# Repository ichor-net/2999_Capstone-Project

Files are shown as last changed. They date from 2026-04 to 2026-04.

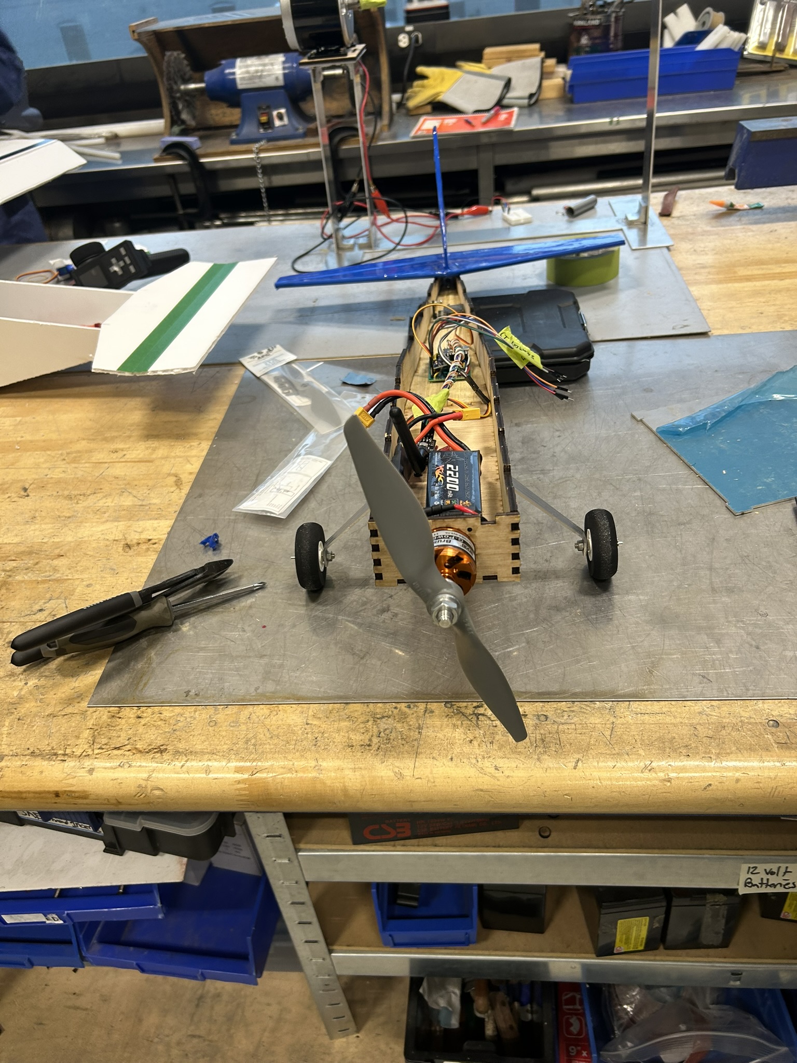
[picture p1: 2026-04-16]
Media/Photos/Assembly (6).JPEG

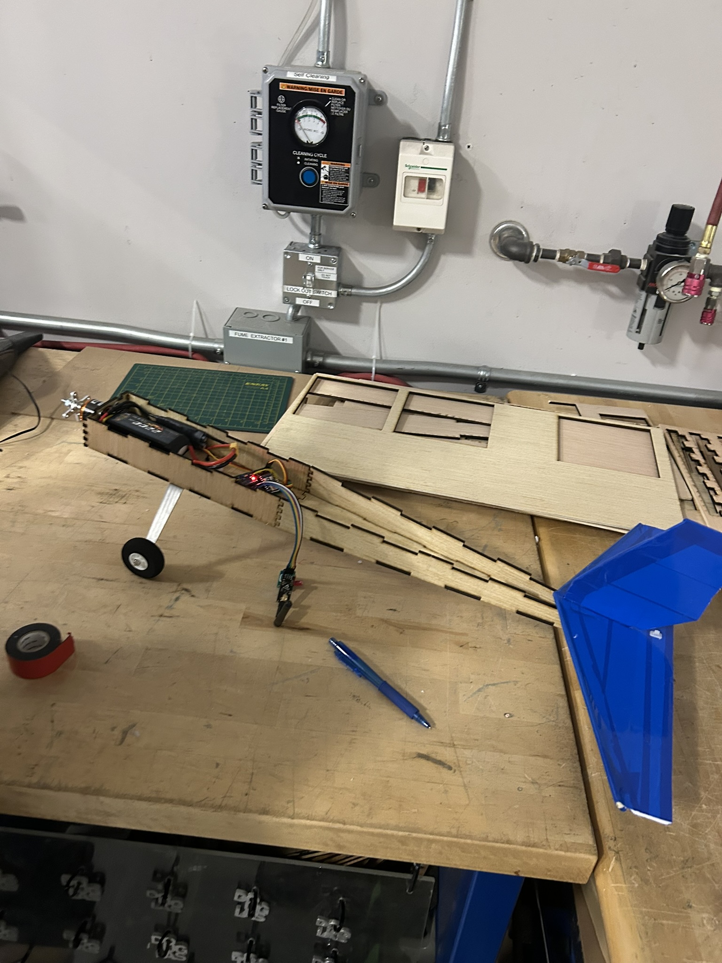
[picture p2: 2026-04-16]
Media/Photos/Assembly (1).JPEG

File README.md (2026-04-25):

# 2999 Capstone Project
Repo for rc plane project files

[Build log](/Reports/Build_Log.md)

All files relating to the project have been organized and uploaded here. I don't really have much to say here •_•

##  
_© 2026 Maximus Larouche, Brendan Morisson. This work is licensed under the Creative Commons Attribution 4.0 International License (CC BY 4.0)._

_You may use, share, and adapt this work for educational purposes, provided proper credit is given to the original authors._

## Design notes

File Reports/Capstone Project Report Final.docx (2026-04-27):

# Remote Controlled Plane and Controller

# ENGR 2999, Douglas College

# Maximus Larouche, Brendan Morrison

# 20/04/2026

# Abstract

This capstone project details the development of a semi-autonomous remote-controlled aircraft and its custom handheld controller. The project transitioned from an initial 3D-printed design to a 1250g laser-cut plywood airframe to ensure structural rigidity for a high-power 4S propulsion system. Aerodynamic analysis utilizing the lift equation resulted in a 62.5-inch wingspan, providing a 55% lift surplus and a significant safety margin for flight testing. The integrated electronics system features a custom RP2350-based control board and a 2.4GHz LoRa radio link, achieving a 1.5:1 thrust-to-weight ratio that places the aircraft in the "sport flyer" category. While core flight systems, including 100Hz PWM signal transmission and tail-dragger landing gear, are fully operational, secondary features such as IMU-based stability and OLED telemetry were deferred to prioritize link reliability. This platform serves as a functional foundation for future multicore software optimizations and real-world environmental validation.

# Introduction

For our project, the moto for our plane is as follows: “it only has to fly, but that doesn’t mean it has to land”. The plane was originally based around the Cessna 182 from which we steered our own design to fit our needs and constraints. The plane’s wings, aerodynamics, and power systems were originally designed for around a 1:1 thrust to weight ratio, however the final weight was around 300g less than our original target, thus resulting in a 1.5:1 ratio, putting it comfortably in the sport flyer category.

The plane uses a 9x6 2-blade propeller with 1450kV brushless motor, powered by a 60A ESC and a 2200mAh 4S LiPo battery. The plane’s communication comes from a 2.4GHz LoRa radio antenna, with a custom soldered RP2350 based control board handling the communication and servo control. The controller uses a slide potentiometer for the throttle and a joystick for the pitch and roll. The controller uses the same MCU and antenna, with a built-in battery and LiPo charging circuit feeding the board.

The software, while functional, is still undergoing improvements and optimizations to allow greater levels of control, and stability. The software is written in Arduino with the ArduinoPico core, with the current version only operating on the single core of the RP2350 on both devices. The software is written to be lightweight and efficient to allow for the most resources to be dedicated to transmitting and receiving data for the antenna.

On the mechanical side the project was initially conceived as a 3D-printed project, the development underwent a significant pivot toward 2D CAD and laser-cut plywood construction to meet fabrication deadlines and ensure a robust platform for the high power propulsion system. The mechanical team focused on optimizing wing area via aerodynamic lift equations and implementing a tail-dragger landing gear configuration to maximize ground clearance. This platform serves as the foundation for the integrated avionics and flight control software.

# Bill of Materials

Item | Quantity | Unit Cost | Cost
Soldering / Prototyping Materials (https://www.amazon.ca/Tnisesm-Connector-Terminal-Prototype-Soldering/dp/B0BWDZK4KZ/ref=sr_1_9?sr=8-9) | 1 (pack) | $16.99 | $16.99
1450Kv Motor (https://www.amazon.ca/D3536-Brushless-Multi-copter-Fixed-wing-Helicopters（D3536/dp/B0D3DWFDG7?th=1) | 1 | $30.81 | $30.81
60A ESC (https://www.amazon.ca/Brushless-2-0mm-fixed-wing-aircraft-helicopter/dp/B0FRM7X984?th=1) | 1 | $44.79 | $44.79
14.8v 2200mAh Battery (https://www.amazon.ca/MELASTA-2200mAh-Airplane-Helicopter-Quadcopter/dp/B01M1ICI8Z) | 1 | $32.99 | $32.99
IMU/Gyroscope module (MPU6050) (https://www.amazon.ca/WayinTop-Gyroscope-Accelerometer-Converter-Arduino/dp/B07P5YXBXV?s=electronics) | 1 | $4.33 | $4.33
Slide Potentiometers (https://www.mouser.ca/ProductDetail/Same-Sky/PTNS2-3010M-B10?qs=6avfeC6zeS4zh8RaIzrOLg%3D%3D) | 1 | $2.55 | $2.55
Toggle Switches (https://www.amazon.ca/Hoypeyfiy-Miniature-Terminals-Automotive-Instrument/dp/B0D89YZPC1) | 1 | $1.07 | $1.07
NRF24L01 PA + LNA Antenna Module (https://www.amazon.ca/CANADUINO®-nRF24L01-2-4GHz-wireless-modem/dp/B06VT3WS66) | 2 | $4.95 | $9.90
WaveShare RP2350-Zero modules (https://www.amazon.ca/Waveshare-RP2350-Zero-Development-Microcontroller-Dual-Architecture/dp/B0DYTVCF2H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) | 2 | $11.50 | $22.99
Joystick Modules (https://www.amazon.ca/Partstower-Joystick-Breakout-Arduino-arduino/dp/B06Y1TG2QL?s=electronics) | 1 | $5.75 | $5.75
MG90s 9g Servos | 3 | ~$4.43 | ~$13.30
9x6 Two Blade Propeller | 1 | $8.90 | $8.90
Miscellaneous electrical components (already had / found them) | - The Insides of a CAT6 Ethernet Cable (wire) - SSD1306 128x84 OLED Display (1x) - EC11 Rotary Encoder (1x) - XL6009 Boost Converter (1x) - TP4056 Battery Charger (1x) - Scavenged Lithium Ion Cell (1x) - 10k Resistors (5x) - 100uF Electrolytic Capacitor (2x) - 10nF Ceramic Capacitors (7x)
Landing Gear (https://www.amazon.ca/dp/B01KRIDXXA?ref=ppx_yo2ov_dt_b_fed_asin_title) | 1 | $21.99 | $21.99
Packing Tape (https://www.princessauto.com/en/2-in-x-100-m-packing-tape-assorted-colours/product/PA0009523648) | 1 | $2.99 (ON SALE) | $2.99
Foam Board (https://www.dollartree.com/readi-board-white-foam-boards/809955) | 3 | $1.25 | $3.75
Control Surface Hardware (https://www.amazon.ca/dp/B0CR76BYXQ?ref=ppx_yo2ov_dt_b_fed_asin_title) | 1 | $18.99 | $18.99
¼” Wooden Dowel (https://www.homedepot.ca/product/alexandria-moulding-hardwood-dowel-1-4-in-x-48-in-blue/1000115241) | 1 | $3.97 | $7.94
Miscellaneous mechanical components (already had / found them) | - ~500g Plywood - M3 Bolts, Nuts, Lock Washers (x6) - M4 Bolts, Nuts (x2)

Total Cost: $250.03

# Design and Changelog

## Mechanical Systems

A. Specifications:
1. Wing Loading and Lift: For a 62.5-inch wingspan with a 7-inch chord, the total wing area is approximately 437.5 square inches or 0.2823 square meters. At a total weight of ~1250g, the wing loading is low enough to allow for stable flight at speeds achievable by a 1450KV motor and a 9-inch propeller.
2. Structural Material: The fuselage is constructed from 5mm laser-cut plywood using friction fit construction with a small caveat. This provides the necessary torsional rigidity to support the battery and motor torque that wouldn’t be possible using only foam in the fuselage. The small caveat is the friction fit in the middle of the plane started to fail upon final assembly and is now aided with tape and epoxy along the area that joins together.
3. Landing Gear Configuration: A tail-dragger configuration was selected to maximize the propeller clearance (~5 inches) and simplify assembly due to time constraints. This configuration requires the main gear to be positioned 3 inches ahead of the Centre of Gravity to prevent “nosing over” during taxi.
4. Propeller Clearance: For a 9-inch propeller, a minimum ground clearance of 0.5 inches at a level position is required. In the three-point stance, the tail-dragger setup further increases this clearance to ~2.5 inches, protecting the drivetrain during takeoff.
5. Control Surface Proportion: The elevator and ailerons were designed to be approximately 30% of the wing and horizontal stabilizer chord respectively. This ratio is considered good practice in RC Plane design to ensure sufficient pitch authority for a short-couple 28-inch (0.700m) fuselage without overwhelming the 9g servos.
B. Math:
1. A primary objective of the design phase was determining the optimal wing area (S) required to generate sufficient lift for the airframe. The design was calculated based on an initial target mass of 1.5 kg to provide a conservative safety margin. In the absence of wind tunnel data for the specific Armin wing profile, established aerodynamic constants and conservative RC aircraft coefficients were utilized in the lift equation. This "worst-case" design approach ensured that the resulting 62.5-inch wingspan would possess a substantial lift surplus, accommodating the final system weight while maintaining a low stall velocity for safe flight testing.

S=Minimum Wing Area

L=Lift=(1.50 kg)(9.81m/(s^2))=12.3 N

ρ=Air Density=1.225(kg)/(m^3)

v=Target Takeoff Speed=10 m/s

C_L =Max Coefficient of Lift=1.1

L=1/2ρv^2 SC_L

S= (2L)/(ρv^2 C_L)= (2(12.3))/((1.225)(10)^2 (1.1))=0.182 m^2 ≈282 in^2

Before construction, the minimum wing area (S) was calculated using the lift equation, assuming a target takeoff velocity of 10 m/s and a Coefficient of Lift of 1.1. While the mathematical minimum area required to support the mass was, a design area of (a 62.5-inch span) was selected. This provides a 55% lift surplus, lowering the stall speed and providing a broader safety margin for manual flight testing. Furthermore, this dimension was strategically chosen to align with the standard stock lengths of the foam board material, optimizing the building process by eliminating the need for span-wise cuts and reducing potential points of structural weakness at the wingtips.

The following is the changelog on the mechanical side:

Part | Description | Change List | Conclusions

Fuselage

Front

The front/motor mount section of the aircraft

RCPlaneSkeletonFront1

- First draft of the front bringing the 3d sketch to reality

RCPlaneSkeletonFront2

- Added cross members to the area that connects to rest of fuselage to increase strength (includes improved geometry)

RCPlaneSkeletonFront3

- Improved Geometry

RCPlaneFront1

- Design switch from 3d modelling and printing to 2d CAD and laser cutting

RCPlaneFront2

- Added bolt holes to mount the motor to the front

RCPlaneSkeleton(Front/Middle/Tail) Conclusions:

- Entering the project with limited 3D modeling experience presented significant challenges, causing the initial design phase to exceed the projected timeline before a presentable model was achieved.
- The failure of the initial 3D-printed fuselage acted as a critical turning point. Recognizing that complex 3D modeling was no longer feasible within the remaining timeframe, the design philosophy shifted to 2D CAD and laser cutting. This allowed for the utilization of familiar fabrication methods to maintain project momentum.

RCPlane(Front/Top) Conclusions:

- Transitioning to laser-cut plywood proved to be the correct strategic decision. Although this resulted in a more utilitarian and less aerodynamic aesthetic, it enabled the mechanical team to rapidly produce a functional prototype by leveraging core engineering principles and prior fabrication experience.

Fuselage Middle

The middle section of the fuselage responsible for holding most of the avionics

RCPlaneSkeletonMiddle1

- First draft of the front bringing the 3d sketch to reality

RCPlaneSkeletonMiddle2

- Shortened the geometry as initial design was too large to 3d print in one piece

RCPlaneSkeletonMiddle3

- Added cross members

RCPlaneTop1

- Design switch from 3d modelling and printing to 2d CAD and laser cutting. Implemented a live hinge to create a seamless, strong one-piece fuselage

RCPlaneTop2

- Scrapped the live hinge idea and shortened to original 3d sketch geometry

RCPlaneTop3

- Added bolt holes and area for servo wires from wings to connect to microcontroller in fuselage. This area also acts as cooling for the battery and esc and lets antenna reach exterior of plane

Fuselage Tail | The tail section of the fuselage | RCPlaneSkeletonTail - First draft of the front bringing the 3d sketch to reality RCPlaneSkeletonTailFront - Shortened the geometry as initial design was too large to 3d print in one piece RCPlaneSkeletonTailRear1 - Shortened the geometry as initial design was too large to 3d print in one piece RCPlaneSkeletonTailRear2 - Improved Geometry
Wings and Horizontal Stabilizer | Wings, horizontal stabilizer and control surfaces that create the lift for the plane | | Definitive conclusions remain pending successful flight testing. While the integrated systems currently function as intended, dynamic flight loads present risks to the wing and stabilizer connections. To mitigate potential failure, epoxy joints and bolt interfaces have been reinforced, ensuring structural integrity can withstand the aerodynamic stresses of the maiden flight.
Landing Gear | The landing gear responsible for taxiing on runway | | The initial tricycle landing gear was replaced with a tail-dragger configuration to streamline assembly under project time constraints. For future refinement, integrating foam dampening on the rear caster wheel would significantly reduce motor-induced vibrations, improving ground handling and ensuring a more stable taxi during the takeoff roll.
Servos and Control Linkages | Responsible for moving the control surfaces to maneuver during flight | | High-gauge steel pushrods with Z-bend attachments were utilized to translate servo rotation into surface deflection. While this interface was stress-tested to minimize "slop" and prevent aerodynamic flutter from the 4S prop-wash, the linkages remain high-maintenance components. Due to their precision-dependent nature, constant inspection and manual tensioning are required to maintain flight safety and prevent mechanical drift.

## Electrical Systems

A. Main Motor Power System Specifications:
  1. Power Input and Output: The motor’s maximum ratings are 650W at 14.8V (4S battery). This motor is then paired with a 60A ESC (maximum of 6S) and a 2200mAh 4S battery which is capable of 50C bursts. The ESC and battery were selected to give enough headroom for any power surges from the motor, acting as insurance for our first plane.
  2. Propeller and Thrust Estimation: Our original maximum weight was decided to be 1500g, meaning that all parts were selected with that in mind. A 9x6 propeller was the appropriate choice for our motor and weight class. With our motor’s unloaded maximum RPM being 21,000 RPM, it is calculated that at 75% efficiency (13,200 RPM) the static thrust with our propeller will be 1600g.
B. Math
  1. Minimum Flight Time:

Capacity (C):2200mAh, Maximum Current Draw (I):43A

Time (t)=C/I=(2200mAh)/(43A)*(1Ah)/(1000mAh)=0.05h=3 minutes

  2. Static Thrust:
    a. Prop Diameter: 9 Inch
    b. Prop Pitch: 6 Inch
    c. Prop Static Rpm: 13,200 RPM
    d. Supply Voltage: 14.8V
    e. Supply Current: 43A

(Results):

    f. Estimated Static Thrust: 1638g
    g. Supplied Power: 636W
    h. Static Efficiency: 74.5%

An online calculator was used, Link: https://rcplanes.online/calc_thrust.htm.

The design and behaviour of the controller and plane circuits are essentially the same from the first and last versions (not including the prototypes in between). The communications reliability was the biggest upgrade between the two versions with it being optimized for longer ranges. For the sake of time, features from the first version were left unprogrammed (multicore, display, gyroscope). If a part is mentioned (IMU, display) then assume it is the same part from the previous version if not specified.

### Controller

V1

Associated Files:

RC-Plane_controller.ino

The first version was designed to only test the functionality of the antenna between the controller and a mock plane. The controller would transmit the joystick and throttle positions and receive the IMU data from the plane with the antenna. The controller would then draw the positions of the analog controls, the IMU data, and the connection status with the plane on the OLED display. The components in the circuit consisted of the following:

- WaveShare RP2350-Zero (1x)
- NRF24L01 PA + LNA Antenna Module (1x)
- Joystick Module (1x)
- Slide Potentiometer (1x)
- SSD1306 128x64 OLED Display (1x)
- 10nF Ceramic Capacitors (3x)

V2 (Final)

Associated Files:

controller.ino

Controller_Final.kicad_pro

The second version kept all the original components with the new additions being the battery power + charging system and a rotary encoder that was never used in the program. The added components are as follows:

- TP4056 Single Cell Battery Charger (1x)
- XL6009 Boost Converter (1x)
- Lithium Cell (unknown capacity) (1x)
- Toggle switch (1x)
- EC11 Rotary Encoder (1x)
- 100uF Electrolytic Capacitor (1x)
- Additional ceramic caps and resistors

While this version had all these components, the display and rotary encoders were never given functions due to program issues. The controller will send the PWM signals or the motor and servos, along with an RTT timer for determining the input latency. The controller now also utilizes the microcontroller’s on-board LED for displaying the connection status.

Final Controller Behaviour Description:

On startup, the controller will turn on the on-board LED and begin the antenna and serial communication. The serial communication is only for debugging purposes and displays the values being written to the motors, RTT, link status, and program runtime. Once initialized, the controller will attempt to connect to the plane until a link is established, when the link is lost or unavailable there is a 100ms timeout before it is considered lost which it will then change the colour of the status LED to red. While the link is established (the LED is green), the controller will read the analog inputs, convert the inputs into the required microsecond values for the motors, and transmit those values at 100Hz to the plane, which is double the frequency of the motor PWM signals. When converting the analog inputs to PWM signals, the controller has hardcoded trim and signal range values that it uses. The controller will always be looping in one of these two states and always listening for any transmissions from the plane.

The screen and rotary encoder were not given functionality in the final version as the coding required was too complex in the time left after this version was assembled. The screen was supposed to display real time data on the status of the plane and have a menu for modifying the trim and range values of each of the motors. The rotary encoder was meant to be the input for that, with the rotary encoder’s switch acting as a selection button.

### Plane

V1 (Mock Plane) Associated Files: RC-Plane_plane.ino | The first version of the plane, the “mock plane”, was meant to only act as a plane by receiving the analog control data and transmitting the IMU data. It would draw a mirror of the controller’s display to show that it was properly receiving the data. The circuit consisted of the following: - Waveshare RP2350-Zero (1x) - NRF24L01 PA + LNA Antenna Module (1x) - SSD1306 128x64 OLED Display (1x) - MPU6050 Inertial Measurement Unit (1x) This was built to test the functionality of the antenna.

V2 (Final)

Associated Files:

plane.ino

Plane_Final.kicad_pro

The second version was fully rebuilt as a soldered control board with pinouts for each module to reduce its size and weight. The board uses a mix of male and female pin headers so that all the on-board modules can be removed and all the external modules can be disconnected from the board. The control board consists of just the microcontroller and the IMU, with the microcontroller’s on-board LED displaying the connection status. The antenna is detached so that it can be optimally positioned, the antenna cable also has grounded cable shielding. The control board has five PWM channels, one for the motor and 4 for servos (we only used 3). The motor channel connects to the ESC which powers the board from the BEC (5v) and supplies power to the servos. The control board circuit consists of the following components:

- Waveshare RP2350-Zero (1x)
- MPU6050 Inertial Measurement Unit (1x)

The antenna is a detached module with the following:

- NRF24L01 PA + LNA Antenna Module (1x)
- 10nF Ceramic Capacitors (1x)
- 100uF Electrolytic Capacitor (1x)

The rest of the plane consists of:

- 1450Kv Brushless Motor (1x)
- 60A ESC (1x)
- 2200mAh 4S 14.8V Lithium Battery (1x)
- MG90s Servos (3x)

The antenna and electromechanical components are adhered or mounted to the plane.

Final Plane Behaviour Description:

On startup the plane will turn on the on-board LED, begin the serial debug output, and initialize the antenna. After initializing, the plane will then wait for the link with the controller to be established. Once the connection is established (LED set to green), the plane will begin receiving the motor values and will continuously write them to the motors while the link is established. Additionally, the plane will transmit IMU data which was changed to being just an 8-bit counter. When the connection is lost (LED set to red), the plane will cut the motor and set all the servos to their default position (currently flat), the plane will stay in this state until the link is reestablished. This is the whole loop.

During testing it was found that the IMU was blocking the loop, leading to the plane being unable to establish a consistent connection with the controller. Because of this, the IMU was taken out of the loop so that it no longer is blocking, and because there was already a set packet structure the “IMU data” was replaced with a looping 8-bit counter so that minimal changes had to be made. If the IMU’s functionality would be restored, the safest way it would be done is running it on the second core with a transmission memory buffer, this wasn’t done for the same reason as the controller’s display.

# Conclusion

The mechanical phase of this project successfully transitioned a conceptual design into a functional, 1250g prototype aircraft. By pivoting from 3D printing to laser-cut plywood, the team achieved the necessary torsional rigidity required to support high-torque motor operations while maintaining a manageable fabrication timeline. Mathematical validation through the lift equation ensured a 55% lift surplus, providing a substantial safety margin for upcoming flight trials.

On the electronics side, the first and second versions were successful, with some features unfortunately needing to be cut from the final version. While running and operational, the code would need to be refined and optimized in a future version along with multicore support for handling peripherals at both ends. At the ends of the final version, focusing on getting the plane operational was the best option. The remaining uncertainty is the antenna and it’s link stability as while it is rated for up to 1100m, during antenna testing it was found that it may only be effective in low noise environments or when the transmitter and receiver are aligned.

While the airframe and propulsion systems are fully integrated, final conclusions regarding flight performance remain pending the results of the maiden test flight. Future iterations will focus on refining the control linkages to reduce manual maintenance and implementing vibration dampening in the landing gear. Combined with the software and avionics integration, the current progress demonstrates a viable platform for stable, remote-controlled flight.

# References

Jason9198, & Instructables. (2017, October 14). Designing and building beautiful RC Airplane. Instructables. https://www.instructables.com/Designing-and-Building-Beautiful-RC-Airplane/

Experimental Airlines. (2012, April 22). ARMIN WING CONSTRUCTION: start-to-finish process with links to detail videos. YouTube. https://www.youtube.com/watch?v=karr67ZYho4&t=99s

APlane, & Instructables. (2020, February 22). Design & build your own electric RC airplane. Instructables. https://www.instructables.com/Design-Build-Your-Own-Electric-RC-Airplane/

Estimate propeller static thrust. (n.d.). https://rcplanes.online/calc_thrust.htm

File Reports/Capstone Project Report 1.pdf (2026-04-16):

# ENGR 2999 Progress Report 1

# Project Introduction

For our ENGR2999 Capstone project we will be designing and fabricating a RC airplane that responds to the user interface of a joystick and throttle to control motor power and flap control. Our project block diagram is shown below.

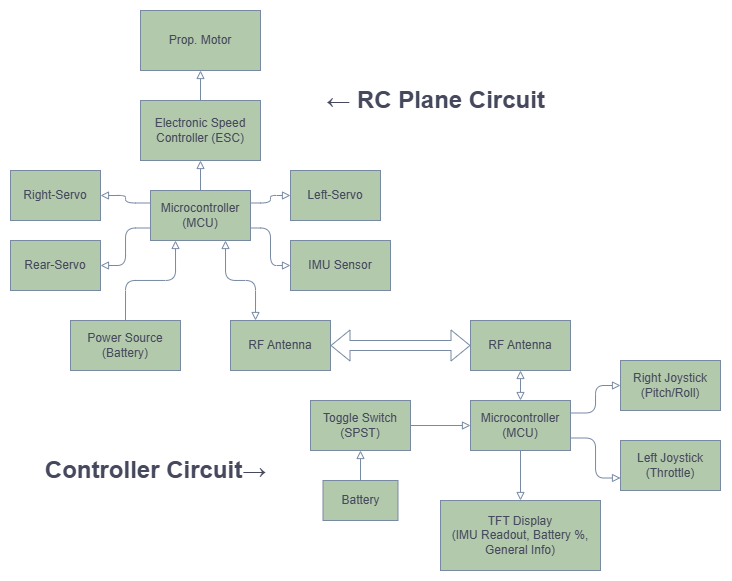
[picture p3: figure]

# Task Breakdown

Our development process will comprise the following tasks:
1. Component Selection:
a. Which microcontroller (MCU) we will be developing around
b. Picking our control method between the controller and plane (RF, IR…)
c. Miscellaneous component selection:
i. Servos
ii. Control surfaces (joysticks, buttons...)
iii. Sensors (gyroscopes, accelerometers, pressure sensors…)

2. Mechanical Platform Prototyping:
a. Material testing and selection
b. Modelling and prototype fabrication
c. Test fitting and electrical component positioning
d. Estimating/Calculating final expected mass, drag and required thrust
i. Allows for propellor motor, electronic speed controller (ESC) and battery selection.
e. Initial circuit testing and prototyping
i. Prototyping individual circuit functions
ii. Building firmware/program prototype functions
3. Mechatronic Platform Fine Tuning:
a. Continuing iteration on the following:
i. Mechanical design, weight reduction, and aerodynamic optimization. ii. Compiling program functions into single program and debugging.
iii. Preparing full circuit for chassis installation and mechanical integration.
b. Verifying component selections and potentially identifying replacements.
i. Potential issues such as:
1. Overweight components
2. Underpowered actuators
3. Battery over/under capacity (over capacity is relative to weight)
4. Antenna troubleshooting and unknowns
c. Debugging, debugging, debugging…
4. Final testing:
a. Verifying that all systems work
b. Reasonably optimized design and code
c. Final test flight

# Task Schedule

Our team of 2 people will split into two groups with the following flexible division of labour: Brendan Morrison will work on the hardware team. The hardware team will work on:
- Material Selection and Structural Analysis:
- Evaluate strength-to-weight ratios of different materials.
- Perform necessary thrust calculations.
- Mechanical design:
- Develop 2D schematics of interior component packaging and exterior aerodynamic profiles.
- Utilize Inventor Autodesk software to create a full assembly of airframe.
- Use inventor model to calculate centre of gravity to ensure flight stability.
- Mechanical assembly:
- Design custom mounts for motor, servos, and battery tray.
- Ensure control linkages operate smoothly and efficiently.
- Prototyping:
- Utilize 3D printing for quick iterations of structural components.
- Analyze wear and tear after test flights and reinforce components where necessary.

Max Larouche will form the electronics team. The electronics team will work on:
- Selecting electrical components

- Electronics design:
- High-level schematics for developing early design aspects for the plane and circuit.
- Low-level schematics for final circuit setup.
- Electronics assembly:
- Fitting and positioning electrical components in the plane housing.
- Wiring and soldering the circuit.
- Software development:
- High-level design for program execution and task management programs.
- Prototyping individual plane and controller functions.
- Firmware development and debugging.
- Overall electrical design process:
- Prototyping individual circuit subsections and program functions.
- Firmware development and compilation throughout.
- Circuit design, prototyping, iteration, and final assembly.

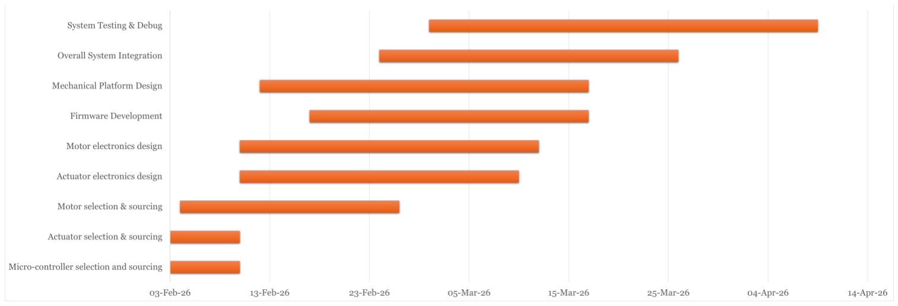
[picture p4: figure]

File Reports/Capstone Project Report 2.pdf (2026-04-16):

# ENGR 2999 Progress Report 2

# Project Recap

Recall, for our ENGR2999 Capstone project we will be designing and fabricating a RC airplane that responds to the user interface of a joystick and throttle to control motor power and flap control. Our project block diagram is shown below.


# Progress Updates

### Fuselage

We have completed the design of the fuselage of the airframe. This has taken longer than expected as we have had to change the original plan of 3d printing the fuselage which failed and have now pivoted to a laser cut plywood approach shown both below. One upside of the finger jointed plywood over the 3d print is it provides superior torsional rigidity for our powerful motor.

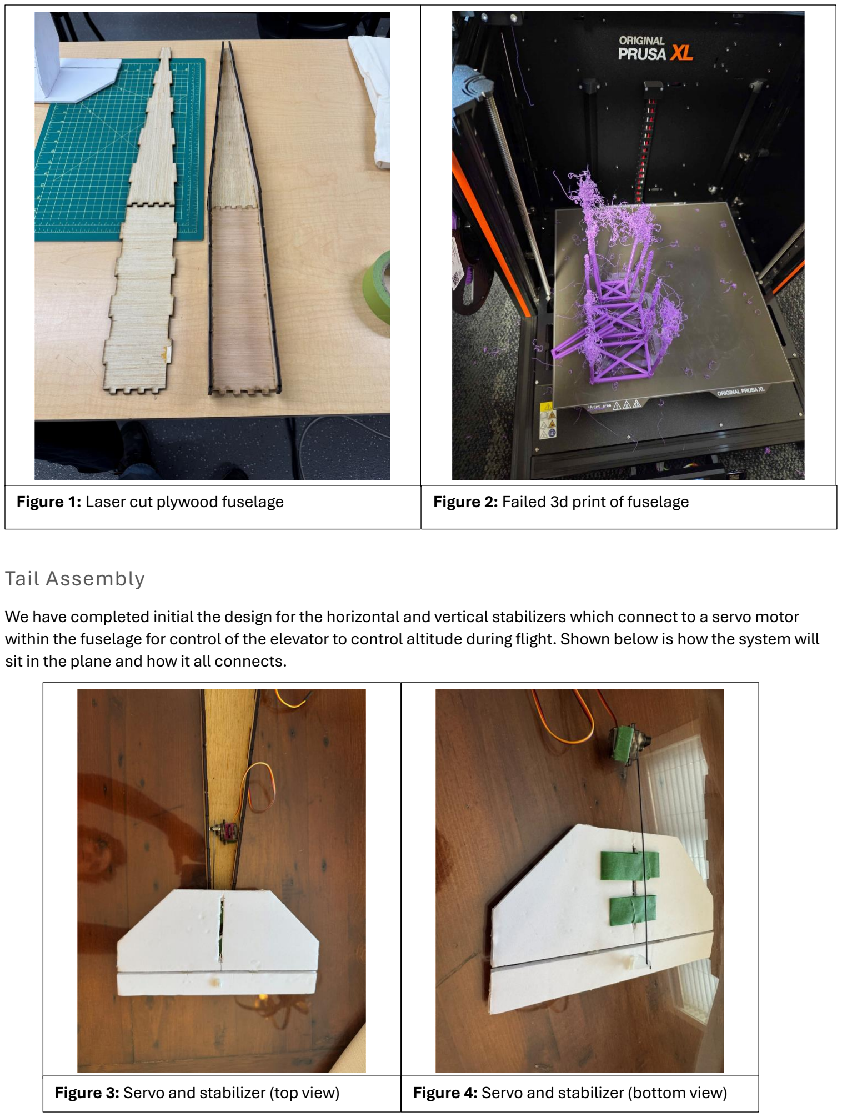
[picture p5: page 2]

### Tail Assembly

We have completed initial the design for the horizontal and vertical stabilizers which connect to a servo motor within the fuselage for control of the elevator to control altitude during flight. Shown below is how the system will sit in the plane and how it all connects.

Figure 1: Laser cut plywood fuselage | Figure 2: Failed 3d print of fuselage
Figure 3: Servo and stabilizer (top view) | Figure 4: Servo and stabilizer (bottom view)

### Power Train

Our aircraft will be powered by a DYS D3536 brushless motor connected to a 60A DYS ESC and a Melasta 4S 14.8 V battery. This power unit combo was selected to give us plenty of wiggle room in the weight of the aircraft and now that the heavier plywood is being used perfectly demonstrates why we went with the more powerful setup. The green masking tape seen in the photos is for initial prototyping and layout, and that final assembly will use mechanical fasteners or epoxy to ensure high-vibration resistance.

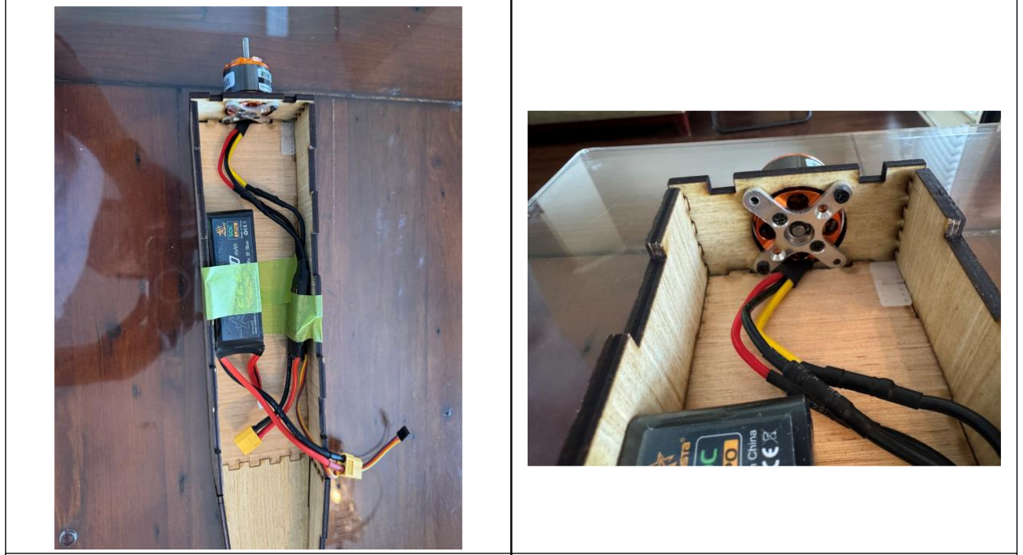
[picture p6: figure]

### Control Board

The control board is based around the Waveshare RP2350-Zero microcontroller which interfaces with the NRF24L01 antenna via SPI and the MPU6050 gyroscope + accelerometer via I2C. The control board is soldered and hand wired to reduce its footprint and weight. The board features 4 servo control channels with the main motor channel providing the board with a 5 volt source through the ESC’s Battery Eliminator Circuit (BEC). The BEC connector follows the same pinout as a servo connector with the only difference being that it’s a power source instead of requiring power. The antenna has a detached breakout board allowing it to be mounted anywhere within the plane at the cost of higher signal interference, which will be resolved with cable shielding. The board is complete and tested but the new firmware still needs to be written.

Figure 5: Motor, battery, and ESC (prototype) Figure 6: Motor mount

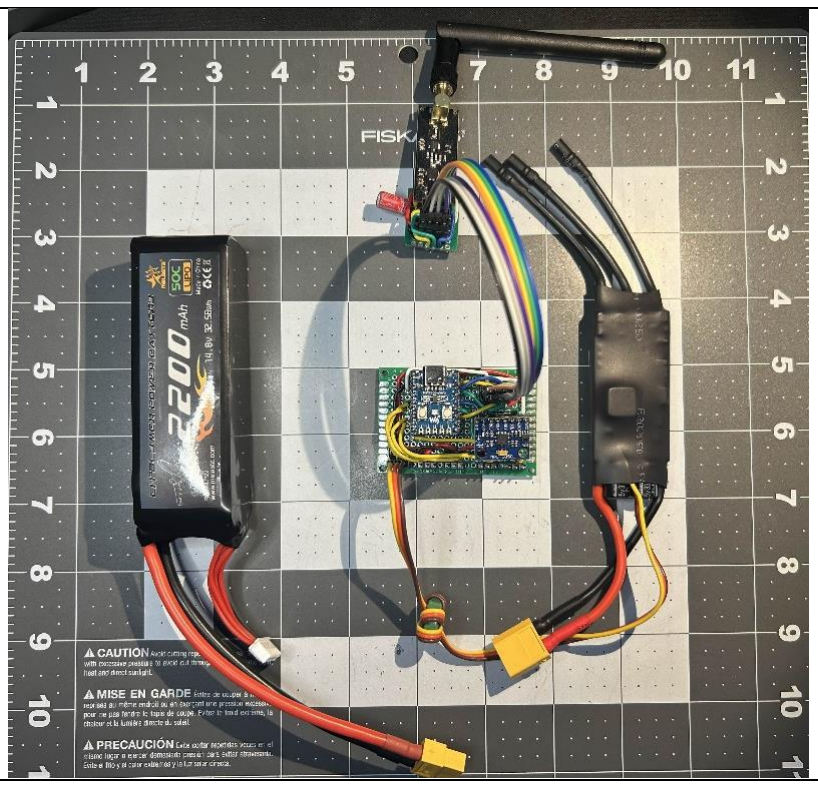
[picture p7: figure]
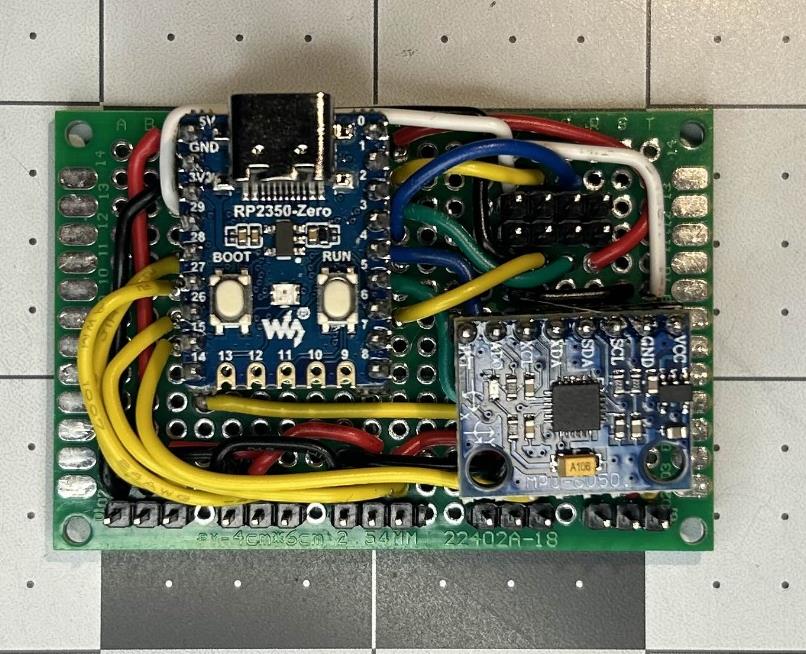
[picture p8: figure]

Figure 7: Mock Circuit With Control Board | Figure 8: Control Board Closeup

### Controller

This is the second iteration of the controller, which is running the same firmware as the first. The controller is based around the Waveshare RP2350-Zero, using a matching NRF24L01 antenna and an SSD1306 OLED display. The control surface is the same as the first, with the addition of a rotary encoder. The controls are as follows: the left slide potentiometer is for throttle control, the joystick on the right is for pitch and roll control, and the rotary encoder is for internal controls such as trim and servo range. The rear of the controller has all the power circuitry, which is as follows: a single salvaged LiPo battery is connected to a TP4056 battery charging module, with a switch between the output of the battery/charger and an XL6009E1 boost converter, which feeds the board 5V. The 5V line then goes through the MCU’s dropout regulator to supply all the 3V3 components on the board. This is the final version of the controller and is surprisingly comfortable to hold.

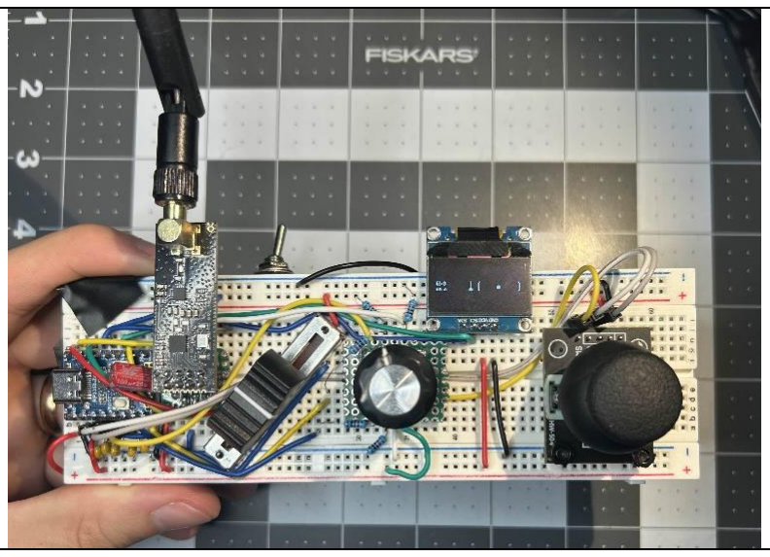
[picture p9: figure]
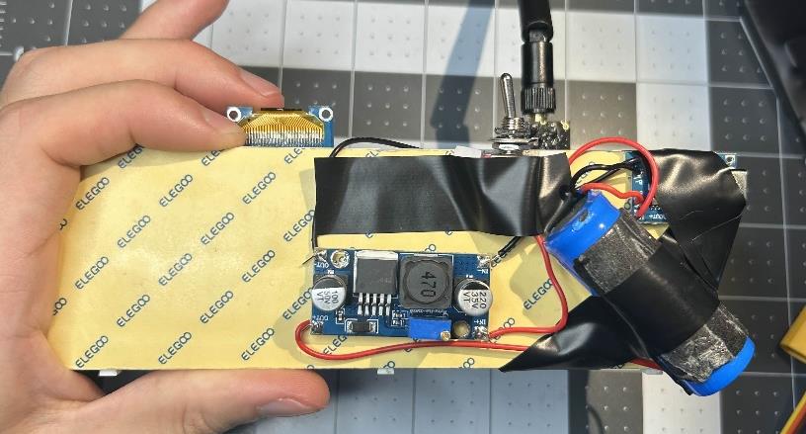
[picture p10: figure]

Figure 9: Final Controller Design (front) | Figure 9: Final Controller Design (back)

### Software

The firmware has gone through several iterations, with the current version rolled back to the stable first version for testing. The next and final version of the firmware will be a slimmed-down version for the sake of time and simplicity. Currently, the display drawing, data and input handling, and trim/range control all need to be rewritten to match the final expected features. Overall, the software is very near completion, and with the final control board and controller completed, the firmware will be very straightforward to write.

# Schedule Updates

So far, our schedule has had the following changes:
1. The 3d printing mishap has moved our Mechanical Platform Design deadline to 02 – Apr – 2026
2. Because the mechanical design is taking longer than expected, system integration and system testing has been pushed to 04 – Apr – 2026
An updated Gantt chart with the above changes is shown below

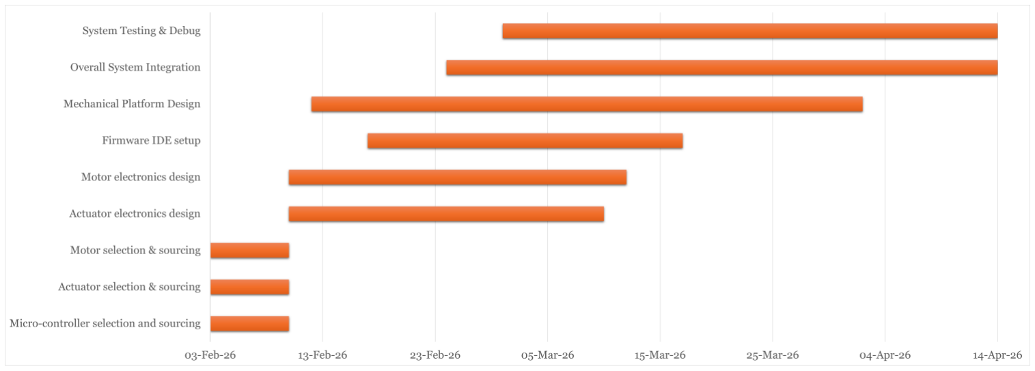
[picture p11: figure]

### Problem Summary

1. Mechanical Design is taking much longer than anticipated. The initial plan was to 3d print most of the aircraft. However, with the deadline fast approaching coming up with a new approach after our failed 3d print was needed and have now switched to a laser cut plywood approach to meet the deadline by 02 – Apr – 2026.
2. As of 02 – Apr – 2026, the calculated take-off weight is approximately 1100g. With our 1450KV motor producing approximately 1500g of thrust, we have maintained a 1.36:1 thrust-to-weight ratio, ensuring sufficient power for a safe climb-out during the maiden flight.
3. Now our project is on track to reach a working prototype by 14 – Apr – 2026. However, a known unknown we have is how much time we will get to test as we might have a scenario where we reach 14 – Apr – 2026. To mitigate the risk of a single-point-of-failure during the April 14th flight, we are prioritizing 'dry-run' ground testing and electronic bench-testing to ensure system reliability before the first takeoff.]
4. While further testing is required, the actual range of the antenna has appeared to be significantly less than advertised, potentially related to the intended use case of the antenna. It was found that the connection stability is significantly related to the relative orientation of the antennae, with alignment being much more important than anticipated, this will be investigated further.
5. A propeller solution has still not been found and will need to be resolved before the end of assembly.

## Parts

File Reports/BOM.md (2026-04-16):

## BOM Links
+ Soldering/Prototyping Materials (1x) -> [(Link)](https://www.amazon.ca/Tnisesm-Connector-Terminal-Prototype-Soldering/dp/B0BWDZK4KZ/ref=sr_1_9?sr=8-9)
 
+ 1450Kv Motor (1x) -> [(Link)](https://www.amazon.ca/D3536-Brushless-Multi-copter-Fixed-wing-Helicopters（D3536/dp/B0D3DWFDG7?th=1)
 
+ 60A ESC (1x) -> [(Link)](https://www.amazon.ca/Brushless-2-0mm-fixed-wing-aircraft-helicopter/dp/B0FRM7X984?th=1)
+ 2200mAh Battery (1x) -> [(Link)](https://www.amazon.ca/MELASTA-2200mAh-Airplane-Helicopter-Quadcopter/dp/B01M1ICI8Z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)
+ IMU/Gyroscope module (1x) -> [(Link)](https://www.amazon.ca/WayinTop-Gyroscope-Accelerometer-Converter-Arduino/dp/B07P5YXBXV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)
+ Slide Potentiometers (1x) -> [(Link)](https://www.mouser.ca/ProductDetail/Same-Sky/PTNS2-3010M-B10?qs=6avfeC6zeS4zh8RaIzrOLg%3D%3D)
+ Toggle Switches (1x) ->  [(Link)](https://www.amazon.ca/Hoypeyfiy-Miniature-Terminals-Automotive-Instrument/dp/B0D89YZPC1/ref=sr_1_6?sr=8-6)
+ NRF24L01 PA + LNA Antenna Module (2x) -> [(Link)](https://www.amazon.ca/CANADUINO®-nRF24L01-2-4GHz-wireless-modem/dp/B06VT3WS66?source=ps-sl-shoppingads-lpcontext&psc=1&smid=A29AOP4GIE7DX6)
+ WaveShare RP2350-Zero modules (2x) -> [(Link)](https://www.amazon.ca/Waveshare-RP2350-Zero-Development-Microcontroller-Dual-Architecture/dp/B0DYTVCF2H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)
+ Joystick Modules (1x) -> [(Link)](https://www.amazon.ca/Partstower-Joystick-Breakout-Arduino-arduino/dp/B06Y1TG2QL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)

## Additional Components Used (Found / Contributed / Bought Last-Minute):
+ TP4056 Battery Charger
  
+ XL6009 Boost Converter
+ EC11 Rotary Encoder
+ MG90s 9g Servos (3x)
+ 9x6 Two Blade Propeller
+ Scavenged Lithium Ion Cell
+ The Insides of a CAT6 Ethernet Cable
+ RC Plane Landing Gear Kit

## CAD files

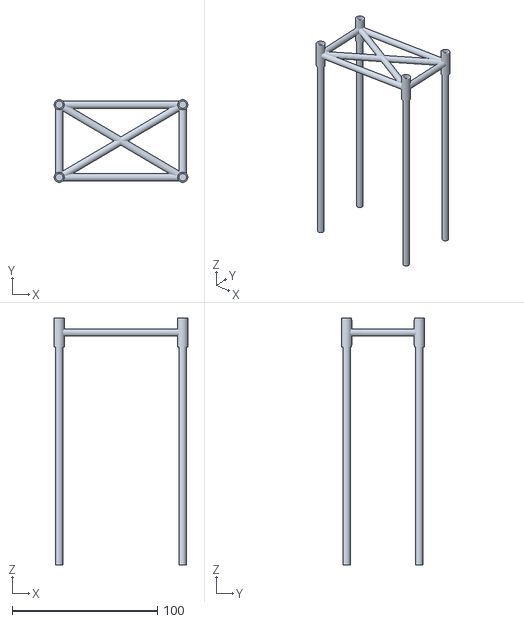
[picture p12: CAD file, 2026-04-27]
CAD Drawings/3D Printing/RCPlaneSkeletonMiddle3.stl
92.0 x 57.0 x 170.0

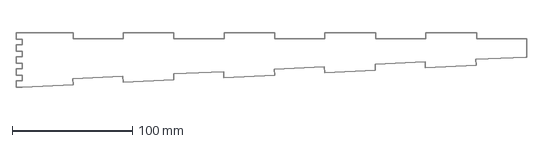
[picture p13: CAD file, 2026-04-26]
CAD Drawings/Laser Cutting/RCPlaneTailSides.dxf
425.0 x 45.3 mm

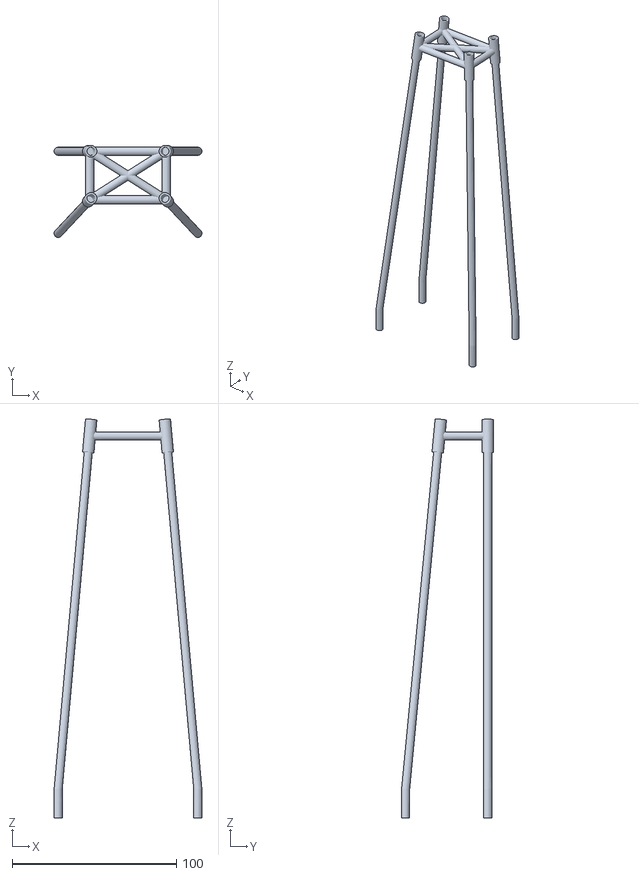
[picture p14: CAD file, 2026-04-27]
CAD Drawings/3D Printing/RCPlaneSkeletonTailFront.stl
90.0 x 56.0 x 242.8

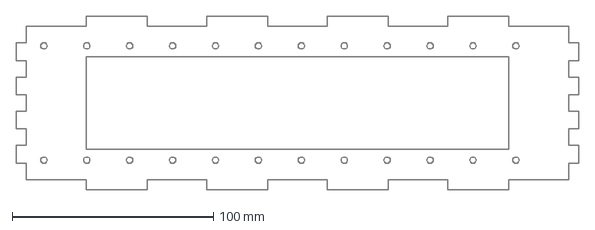
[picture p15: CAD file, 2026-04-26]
CAD Drawings/Laser Cutting/RCPlaneTop3.dxf
279.7 x 86.2 mm

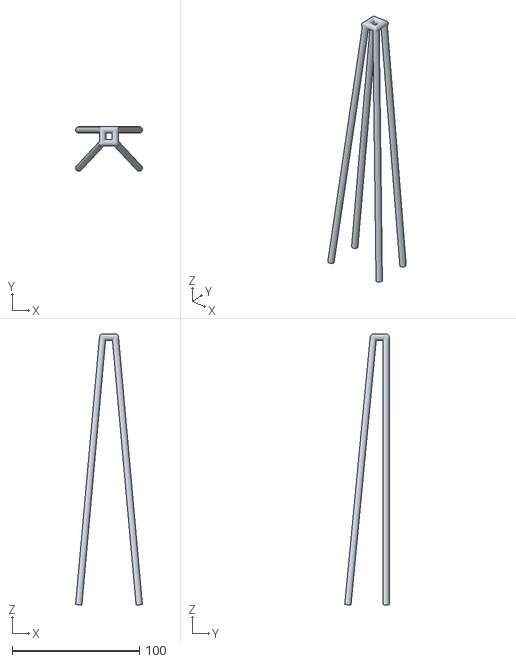
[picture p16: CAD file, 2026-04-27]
CAD Drawings/3D Printing/RCPlaneSkeletonTailRear1.stl
52.5 x 35.0 x 212.8

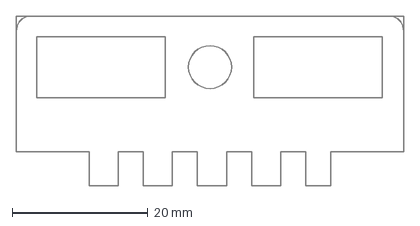
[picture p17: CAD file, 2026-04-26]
CAD Drawings/Laser Cutting/RCPlaneConnectorSide.dxf
57.1 x 25.0 mm

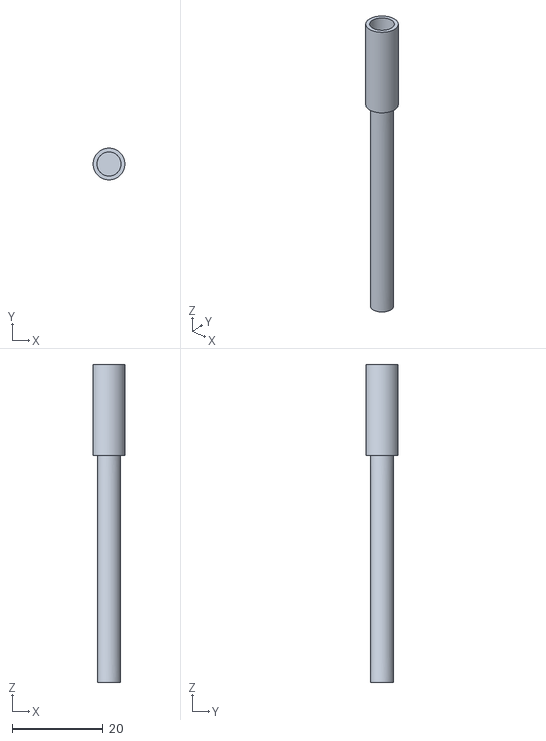
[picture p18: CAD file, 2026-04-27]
CAD Drawings/3D Printing/RCPlaneConnectorTest1.stl
7.00 x 6.99 x 70.0

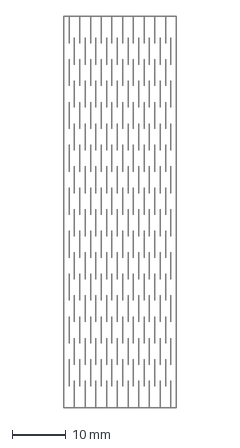
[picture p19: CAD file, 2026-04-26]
CAD Drawings/Laser Cutting/LiveHingeTest1.dxf
21.0 x 73.0 mm

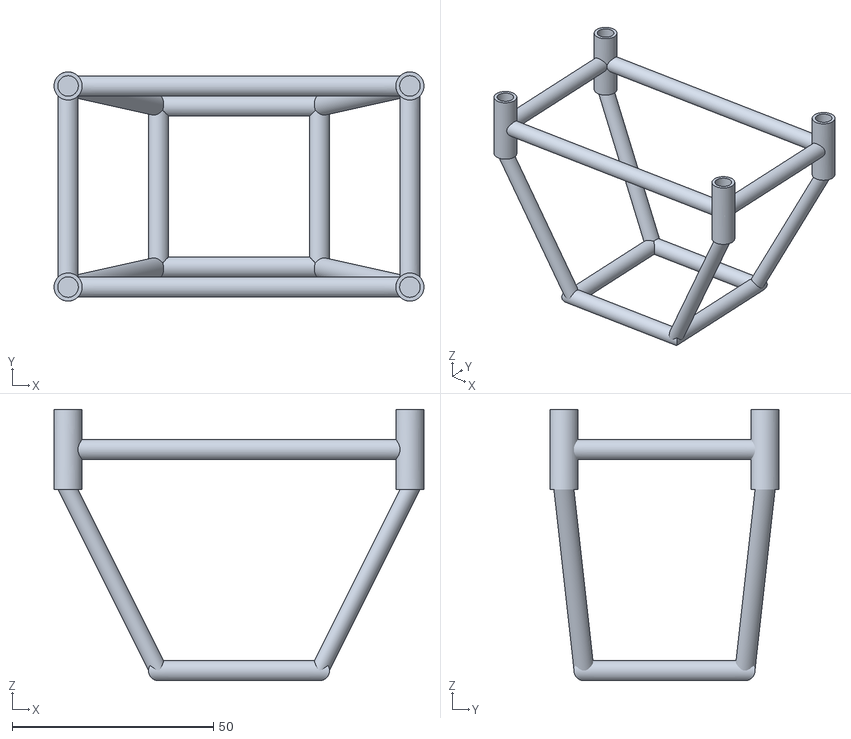
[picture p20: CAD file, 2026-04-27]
CAD Drawings/3D Printing/RCPlaneSkeletonFront3.stl
92.0 x 57.0 x 67.5

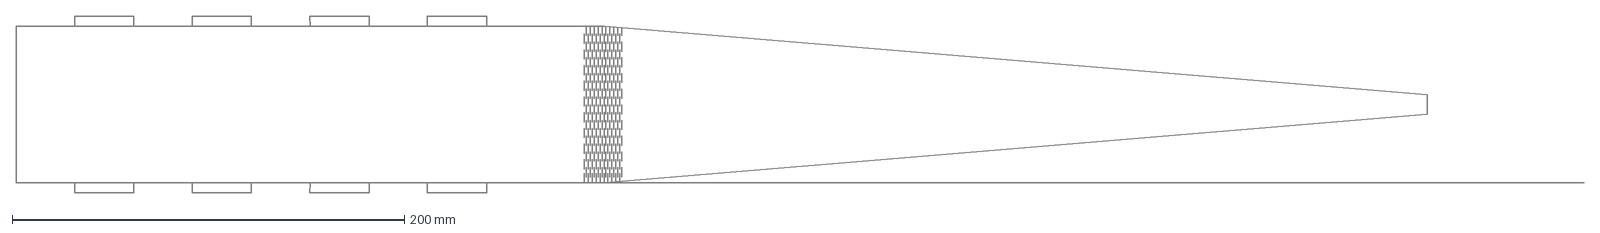
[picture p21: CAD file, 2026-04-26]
CAD Drawings/Laser Cutting/RCPlaneTop1.dxf
800.0 x 90.0 mm

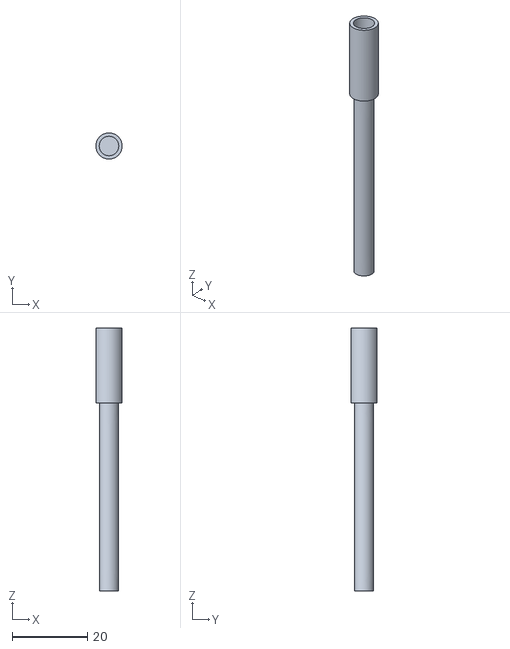
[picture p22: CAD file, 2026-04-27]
CAD Drawings/3D Printing/RCPlaneConnectorTest2.stl
7.00 x 6.99 x 70.0

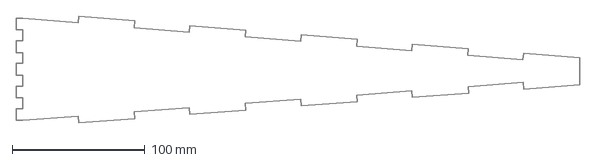
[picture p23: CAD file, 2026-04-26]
CAD Drawings/Laser Cutting/RCPlaneTailTop_Bottom.dxf
424.2 x 80.2 mm

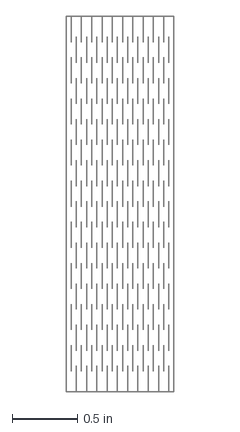
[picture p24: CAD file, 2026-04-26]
CAD Drawings/Laser Cutting/LiveHingeTest1inches.dxf
0.827 x 2.87 in

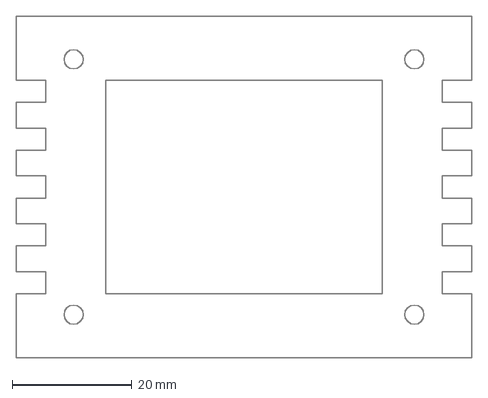
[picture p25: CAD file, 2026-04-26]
CAD Drawings/Laser Cutting/RCPlaneConnectorBottom.dxf
76.2 x 57.1 mm

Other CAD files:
CAD Drawings/Laser Cutting/RCPlaneFront1.dxf
CAD Drawings/Laser Cutting/RCPlaneSides.dxf
CAD Drawings/Laser Cutting/RCPlaneFront2.dxf
CAD Drawings/Laser Cutting/RCPlaneTop2.dxf
CAD Drawings/3D Modelling/RCPlaneAssembly.iam
CAD Drawings/3D Modelling/RCPlaneAssembly1.iam
CAD Drawings/3D Modelling/RCPlaneConnectorTest1.ipt
CAD Drawings/3D Modelling/RCPlaneConnectorTest2.ipt
CAD Drawings/3D Modelling/RCPlaneElevator.ipt
CAD Drawings/3D Modelling/RCPlaneShellTailRear.ipt
CAD Drawings/3D Modelling/RCPlaneSkeletonFront1.ipt
CAD Drawings/3D Modelling/RCPlaneSkeletonFront2.ipt
CAD Drawings/3D Modelling/RCPlaneSkeletonFront3.ipt
CAD Drawings/3D Modelling/RCPlaneSkeletonMiddle1.ipt
CAD Drawings/3D Modelling/RCPlaneSkeletonMiddle2.ipt
CAD Drawings/3D Modelling/RCPlaneSkeletonMiddle3.ipt
CAD Drawings/3D Modelling/RCPlaneSkeletonSketch1.ipt
CAD Drawings/3D Modelling/RCPlaneSkeletonSketch2.ipt
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

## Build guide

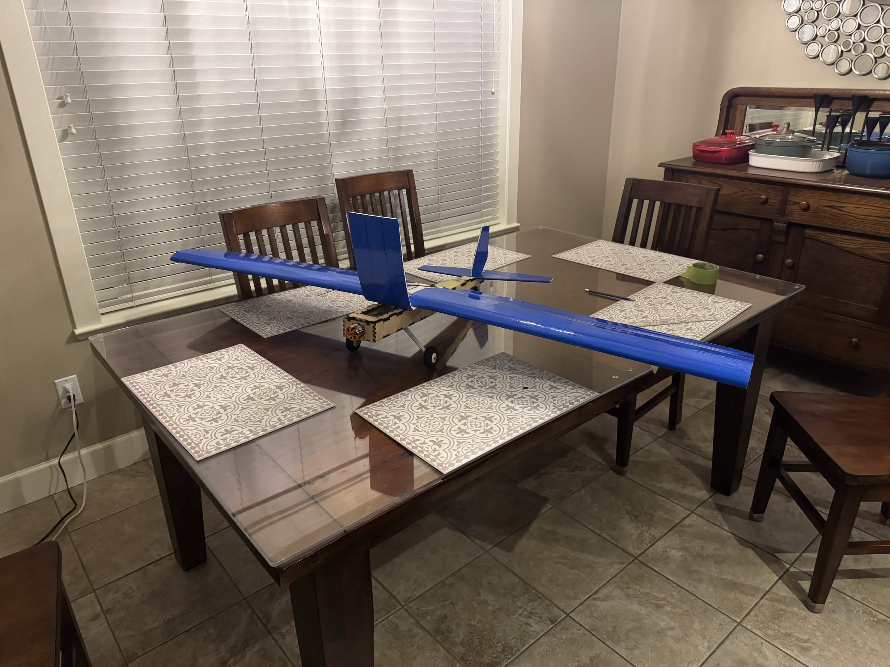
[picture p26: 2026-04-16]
Media/Photos/Test assembly.jpg

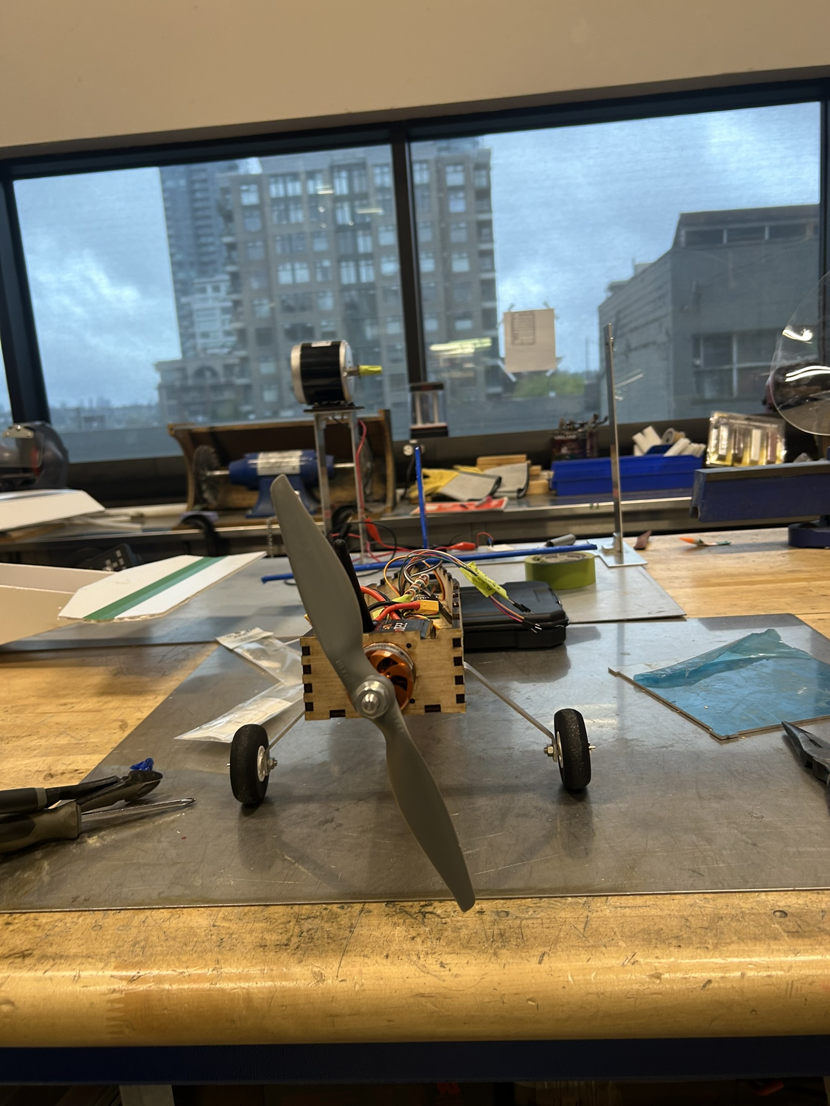
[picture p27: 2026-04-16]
Media/Photos/Assembly (5).JPEG

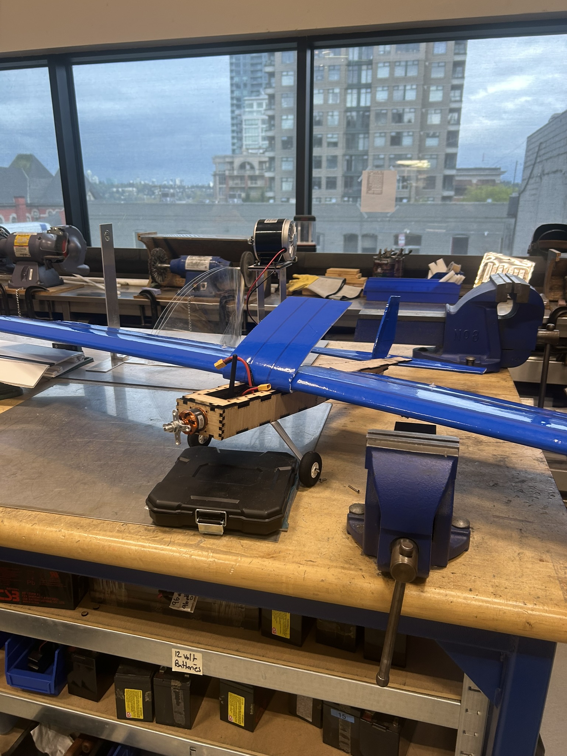
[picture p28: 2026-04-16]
Media/Photos/Assembly (2).JPEG

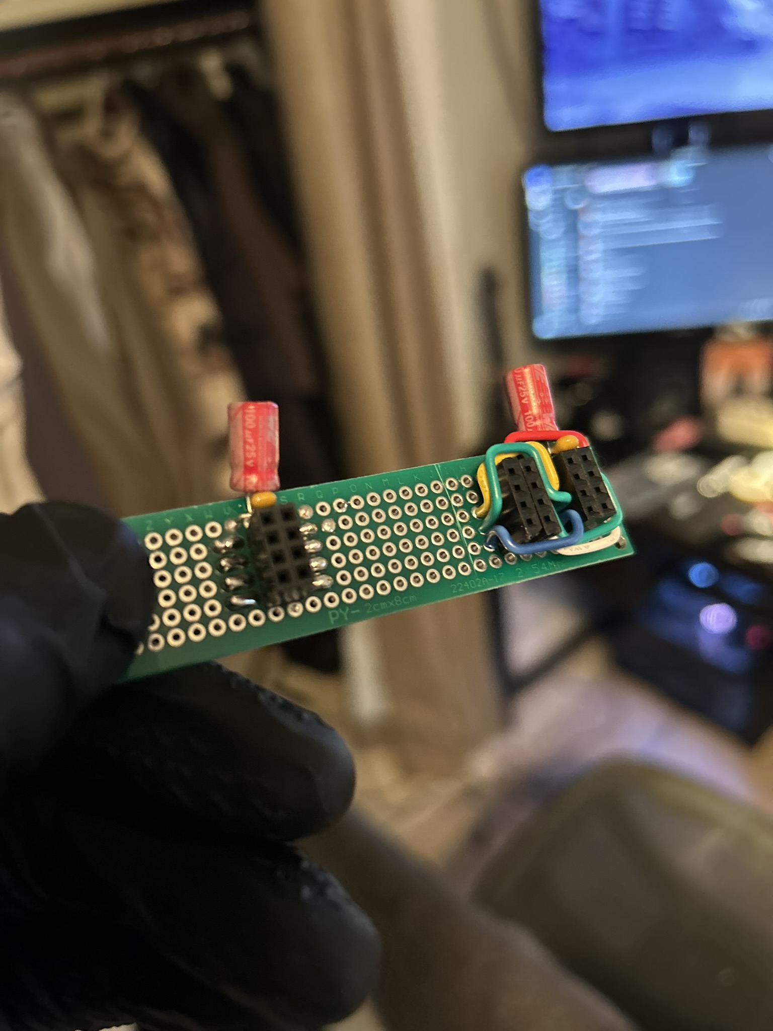
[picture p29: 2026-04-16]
Media/Photos/Antenna Adapter Soldering (2).JPEG

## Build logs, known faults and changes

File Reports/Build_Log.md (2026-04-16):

# RC Plane Build Log
Tracking files and logbook for next features or changes

###  10/03/26:
First nrf24l01 echo prototype. Controller sends inputs to "plane" and plane will echo imu data with RTT. Controller and plane both have 0.96" oled displays for echoed input graphics and IMU readout, with controller also having RTT calculation. Controller and Plane programs are nearly identical.

_ToDo: Need to add motor control code using HW PWM for servos and motors, and programs need to be cleaned up and optimized. Considering multicore to reduce latency_

### 16/04/26:
I forgot to update the build log :(. Final version has been completed as of 14/04/26. The final program had many features cut for the sake of time, unfortunately, but is fully working aside from hardware issues. It turns out the antenna has a significantly shorter range than what was advertised, potentially due to it requiring proper alignment between the two points rather than having more degrees of freedom. The final build did have some fitment issues but is overall very solid, with all control surfaces operating smoothly and as intended. The only potential physical issue is the weight being balanced ore in front of the wings which may cause issues in our first test which has not been scheduled yet.

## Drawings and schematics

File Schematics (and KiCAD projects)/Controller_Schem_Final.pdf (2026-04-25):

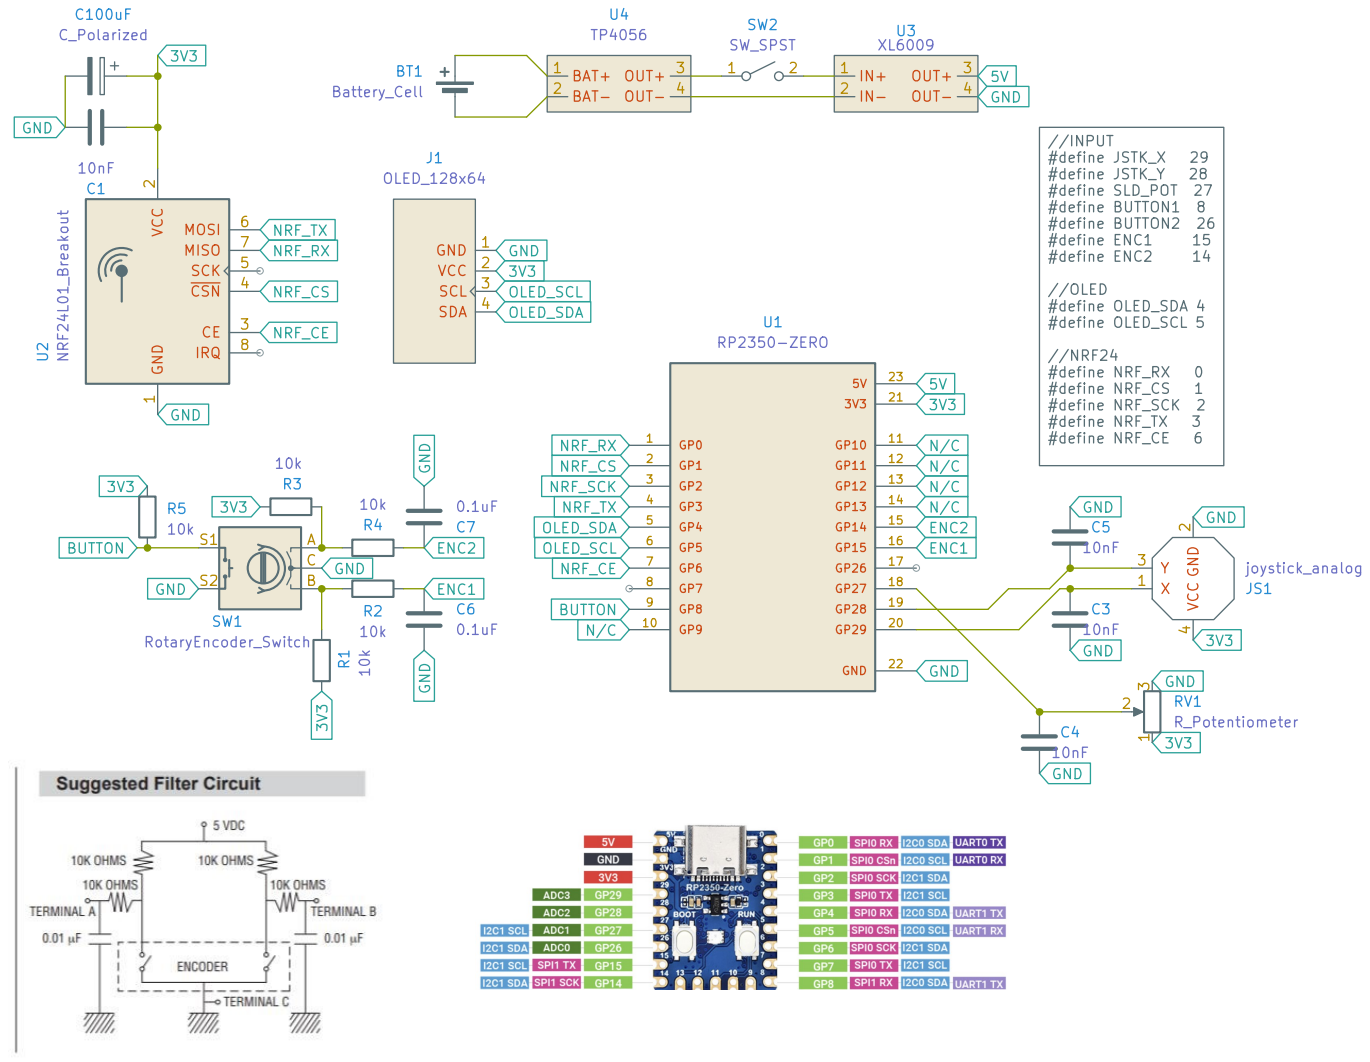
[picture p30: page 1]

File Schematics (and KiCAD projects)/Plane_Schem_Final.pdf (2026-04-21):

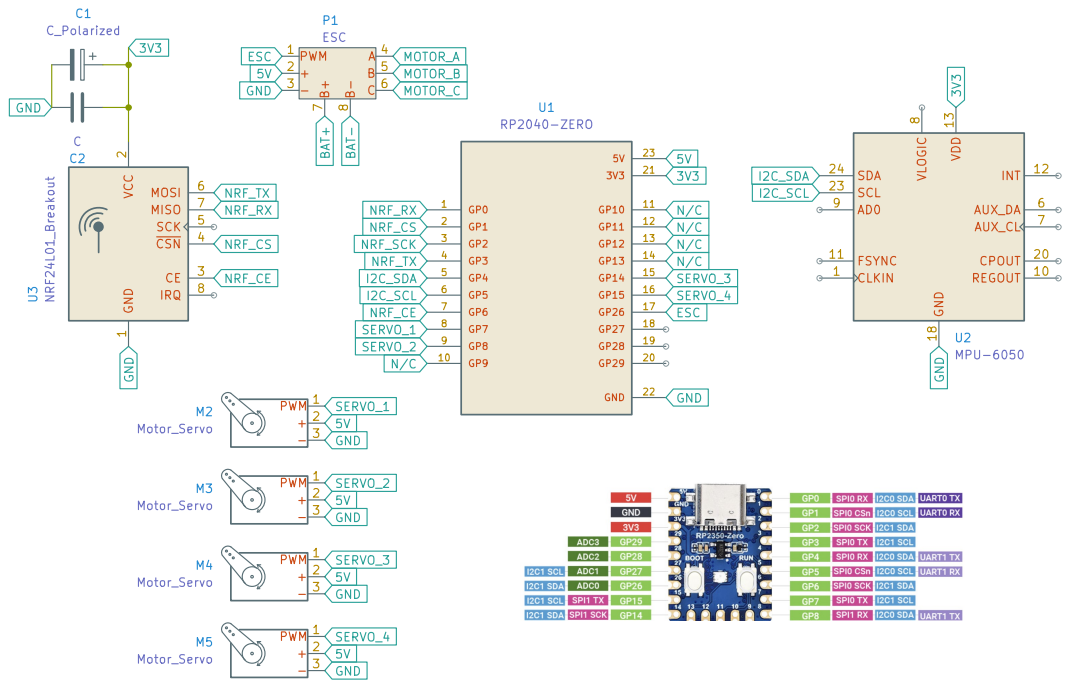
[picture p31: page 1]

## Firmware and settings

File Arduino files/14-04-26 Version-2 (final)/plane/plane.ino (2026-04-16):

#include <Arduino.h>
#include <Wire.h>
#include <RF24.h>
#include <SPI.h>
#include <FastLED.h>
#include <Servo.h>

// ---------------- IMU ----------------
#define IMU_SDA 4
#define IMU_SCL 5
#define MPU_ADDR 0x68

// ---------------- NRF ----------------
#define NRF_RX 0
#define NRF_CS 1
#define NRF_SCK 2
#define NRF_TX 3
#define NRF_CE 6

// ---------------- OUTPUT ----------------
#define PORT_SERVO 27
#define STAR_SERVO 26
#define EL_SERVO   15
#define PROP       28

// ---------------- LED ----------------
#define LED_PIN 16
const int BRIGHTNESS = 120;
CRGB led[1];

// ---------------- DATA ----------------
// rtt_timer is being used as a packet ID / echo tag.
struct __attribute__((packed)) Packet_TX {
  uint8_t gyro_x;
  uint8_t gyro_y;
  uint8_t gyro_z;
  uint8_t rtt_timer;
};

struct __attribute__((packed)) Packet_RX {
  uint16_t servo_write[4];
  uint8_t rtt_timer;
};

static_assert(sizeof(Packet_TX) == 4, "Packet_TX size wrong");
static_assert(sizeof(Packet_RX) == 9, "Packet_RX size wrong");

// ---------------- GLOBALS ----------------
Packet_TX GLOBAL_TX = {128, 128, 128, 0};
Packet_RX GLOBAL_RX = {{1500, 1500, 1500, 1000}, 0};

uint32_t lastLinkTime = 0;
bool linkOK = false;
uint32_t rxCount = 0;
uint32_t txCount = 0;

// ---------------- RADIO ----------------
RF24 radio(NRF_CE, NRF_CS);

byte rxAddr[6] = "CNTRL";
byte txAddr[6] = "PLANE";

// ---------------- SERVO OBJECTS ----------------
Servo servo_port;
Servo servo_star;
Servo servo_el;
Servo esc;

// ---------------- PROTOTYPES ----------------
void input();
bool radioUpdate();
void updateMotor();
void updateLED();
void debugOutput();

// ======================================================
void setup() {
  Serial.begin(115200);
  delay(1000);
  Serial.println("Starting Plane.");

  FastLED.addLeds<WS2812, LED_PIN, GRB>(led, 1);
  led[0] = CRGB(255 - BRIGHTNESS, 255 - BRIGHTNESS, 255 - BRIGHTNESS);
  FastLED.show();

  // Servo / ESC setup
  servo_port.attach(PORT_SERVO);
  servo_star.attach(STAR_SERVO);
  servo_el.attach(EL_SERVO);
  esc.attach(PROP);

  // Safe startup values
  esc.writeMicroseconds(1000);
  servo_port.writeMicroseconds(1500);
  servo_star.writeMicroseconds(1500);
  servo_el.writeMicroseconds(1500);

  delay(2000);  // ESC arm time

  // SPI / Radio
  SPI.setRX(NRF_RX);
  SPI.setCS(NRF_CS);
  SPI.setSCK(NRF_SCK);
  SPI.setTX(NRF_TX);
  SPI.begin();

  if (!radio.begin()) {
    Serial.println("RADIO NOT FOUND");
  } else {
    Serial.println("RADIO FOUND");
  }

  // Same settings that matched your working test
  radio.setPALevel(RF24_PA_HIGH);
  radio.setDataRate(RF24_250KBPS);
  radio.setRetries(3, 5);
  radio.setChannel(108);

  radio.openWritingPipe(txAddr);
  radio.openReadingPipe(1, rxAddr);
  radio.startListening();
  radio.flush_rx();
  radio.flush_tx();

  // IMU
  Wire.setSDA(IMU_SDA);
  Wire.setSCL(IMU_SCL);
  Wire.begin();

  Wire.beginTransmission(MPU_ADDR);
  Wire.write(0x6B);
  Wire.write(0);
  Wire.endTransmission(true);
}

// ======================================================
void loop() {
  // Always poll radio as fast as possible
  radioUpdate();

  static uint32_t lastTick = 0;
  uint32_t now = millis();

  if (now - lastTick >= 10) {   // 100 Hz
    lastTick += 10;

    input();
    updateMotor();
    updateLED();
    debugOutput();
  }
}

// ======================================================
/*
void input() {
  Wire.beginTransmission(MPU_ADDR);
  Wire.write(0x3B);
  Wire.endTransmission(false);

  if (Wire.requestFrom(MPU_ADDR, 14, true) != 14) {
    return;
  }

  Wire.read(); Wire.read(); // ax
  Wire.read(); Wire.read(); // ay
  Wire.read(); Wire.read(); // az
  Wire.read(); Wire.read(); // temp

  int16_t gx = (Wire.read() << 8) | Wire.read();
  int16_t gy = (Wire.read() << 8) | Wire.read();
  int16_t gz = (Wire.read() << 8) | Wire.read();

  // compress gyro to 0..255
  GLOBAL_TX.gyro_x = (uint8_t)((gx >> 8) + 128);
  GLOBAL_TX.gyro_y = (uint8_t)((gy >> 8) + 128);
  GLOBAL_TX.gyro_z = (uint8_t)((gz >> 8) + 128);
}
*/
void input() {
  static uint8_t n = 0;
  n++;

  GLOBAL_TX.gyro_x = n;
  GLOBAL_TX.gyro_y = n + 1;
  GLOBAL_TX.gyro_z = n + 2;
}

// ======================================================
bool radioUpdate() {
  bool gotPacket = false;

  // Drain RX queue, keep newest control packet
  while (radio.available()) {
    radio.read(&GLOBAL_RX, sizeof(GLOBAL_RX));
    rxCount++;
    gotPacket = true;
  }

  if (gotPacket) {
    lastLinkTime = millis();
    linkOK = true;

    // Echo back the packet ID from controller
    GLOBAL_TX.rtt_timer = GLOBAL_RX.rtt_timer;

    radio.stopListening();
    bool ok = radio.write(&GLOBAL_TX, sizeof(GLOBAL_TX));
    radio.startListening();

    if (ok) {
      txCount++;
    }

    return true;
  }

  if (millis() - lastLinkTime > 100) {
    linkOK = false;
  }

  return false;
}

// ======================================================
void updateMotor() {
  static uint16_t current[4] = {1500, 1500, 1500, 1000};

  for (int i = 0; i < 4; i++) {
    uint16_t target;

    if (!linkOK) {
      target = (i == 3) ? 1000 : 1500;
    } else {
      // assuming controller already clamps values properly
      target = GLOBAL_RX.servo_write[i];
    }

    // faster smoothing
    if (i == 3) {
      current[i] = (current[i] + target) / 2;       // throttle: 2-tick
    } else {
      current[i] = (current[i] * 2 + target) / 3;   // surfaces: 3-tick
    }
  }

  servo_port.writeMicroseconds(current[0]);
  servo_star.writeMicroseconds(current[1]);
  servo_el.writeMicroseconds(current[2]);
  esc.writeMicroseconds(current[3]);
}

// ======================================================
void updateLED() {
  if (!linkOK) {
    led[0] = CRGB(BRIGHTNESS, 0, 0);   // red = no valid control packets
  } else {
    uint8_t level = map(GLOBAL_RX.servo_write[3], 1000, 2000, 0, BRIGHTNESS);
    led[0] = CRGB(0, level, 0);        // green brightness = throttle
  }

  FastLED.show();
}

// ======================================================
void debugOutput() {
  static uint32_t lastPrint = 0;
  uint32_t now = millis();

  if (now - lastPrint < 100) return;   // 10 Hz serial output
  lastPrint = now;

  Serial.print("LINK: ");
  Serial.print(linkOK ? "OK" : "LOST");

  Serial.print(" | RX#: ");
  Serial.print(rxCount);

  Serial.print(" | TX#: ");
  Serial.print(txCount);

  Serial.print(" | IN: ");
  for (int i = 0; i < 4; i++) {
    Serial.print(GLOBAL_RX.servo_write[i]);
    if (i < 3) Serial.print(", ");
  }

  Serial.print(" | GYRO: ");
  Serial.print(GLOBAL_TX.gyro_x);
  Serial.print(", ");
  Serial.print(GLOBAL_TX.gyro_y);
  Serial.print(", ");
  Serial.print(GLOBAL_TX.gyro_z);

  Serial.print(" | ECHO_ID: ");
  Serial.print(GLOBAL_TX.rtt_timer);

  Serial.println();
}

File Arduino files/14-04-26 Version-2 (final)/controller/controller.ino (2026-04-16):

#include <Arduino.h>
#include <U8g2lib.h>
#include <Wire.h>
#include <RF24.h>
#include <SPI.h>
#include <FastLED.h>

// ---------------- INPUT ----------------
#define JSTK_X   29
#define JSTK_Y   28
#define SLD_POT  27
#define BUTTON1  8
#define BUTTON2  26
#define ENC1     15
#define ENC2     14

// ---------------- OLED ----------------
#define OLED_SDA 4
#define OLED_SCL 5

// ---------------- NRF24 ----------------
#define NRF_RX   0
#define NRF_CS   1
#define NRF_SCK  2
#define NRF_TX   3
#define NRF_CE   6

// ---------------- LED ----------------
#define LED_PIN 16
const int BRIGHTNESS = 120;
CRGB led[1];

// ---------------- SERVO ORDER ----------------
// 0 = port
// 1 = starboard
// 2 = elevator
// 3 = throttle

// ---------------- HARDCODED SERVO SETTINGS ----------------
// Adjust these directly if you want trim/range changes.
const uint16_t SERVO_TRIM_US[4]  = {1500, 1500, 1500, 1000};
const uint16_t SERVO_RANGE_US[4] = {500, 500, 500, 1000};

// ---------------- DATA ----------------
// rtt_timer is being used as a packet ID / echo tag.
struct __attribute__((packed)) Packet_TX {
  uint16_t servo_write[4];
  uint8_t rtt_timer;
};

struct __attribute__((packed)) Packet_RX {
  uint8_t gyro_x;
  uint8_t gyro_y;
  uint8_t gyro_z;
  uint8_t rtt_timer;
};

static_assert(sizeof(Packet_TX) == 9, "Packet_TX size wrong");
static_assert(sizeof(Packet_RX) == 4, "Packet_RX size wrong");

// ---------------- GLOBALS ----------------
Packet_TX GLOBAL_TX = {{1500, 1500, 1500, 1000}, 0};
Packet_RX GLOBAL_RX = {128, 128, 128, 0};

U8G2_SSD1306_128X64_NONAME_F_HW_I2C disp(U8G2_R2, U8X8_PIN_NONE);
RF24 radio(NRF_CE, NRF_CS);

byte txAddr[6] = "CNTRL";
byte rxAddr[6] = "PLANE";

uint32_t lastLinkTime = 0;
bool linkOK = false;
uint8_t nextPacketId = 0;
uint8_t awaitedPacketId = 0;
uint32_t replyCount = 0;

// ---------------- PROTOTYPES ----------------
void inputHandler(Packet_TX &p);
bool radioHandler(Packet_TX &send, Packet_RX &receive);
void debugOutput(const Packet_TX &p, const Packet_RX &r, bool gotReply);

// ======================================================
void setup() {
  FastLED.addLeds<WS2812, LED_PIN, GRB>(led, 1);
  led[0] = CRGB(255 - BRIGHTNESS, 255 - BRIGHTNESS, 255 - BRIGHTNESS);
  FastLED.show();

  Serial.begin(115200);
  delay(500);
  Serial.println("Starting Controller.");

  pinMode(BUTTON1, INPUT);
  pinMode(BUTTON2, INPUT);

  SPI.setRX(NRF_RX);
  SPI.setCS(NRF_CS);
  SPI.setSCK(NRF_SCK);
  SPI.setTX(NRF_TX);
  SPI.begin();

  if (!radio.begin()) {
    Serial.println("RADIO NOT FOUND");
  } else {
    Serial.println("RADIO FOUND");
  }

  // Same settings that matched your working test
  radio.setPALevel(RF24_PA_HIGH);
  radio.setDataRate(RF24_250KBPS);
  radio.setRetries(3, 5);
  radio.setChannel(108);

  radio.openWritingPipe(txAddr);
  radio.openReadingPipe(1, rxAddr);
  radio.stopListening();
  radio.flush_rx();
  radio.flush_tx();

  Wire.setSDA(OLED_SDA);
  Wire.setSCL(OLED_SCL);
  Wire.begin();

  disp.begin();
  disp.setFont(u8g2_font_5x7_tf);
  disp.setFontPosTop();
  disp.clearBuffer();
}

// ======================================================
void loop() {
  static uint32_t lastTime = 0;
  uint32_t now = millis();

  if (now - lastTime >= 10) {   // 100 Hz
    lastTime += 10;
    radioHandler(GLOBAL_TX, GLOBAL_RX);
  }
}

// ======================================================
void inputHandler(Packet_TX &p) {
  static int sx = 512;
  static int sy = 512;
  static int st = 0;

  // 3-tick smoothing on raw analogs
  sx = (sx * 2 + analogRead(JSTK_X)) / 3;
  sy = (sy * 2 + analogRead(JSTK_Y)) / 3;
  st = (st * 2 + analogRead(SLD_POT)) / 3;

  int x0 = (sx * SERVO_RANGE_US[0]) / 1024 - (SERVO_RANGE_US[0] / 2);
  int x1 = (sx * SERVO_RANGE_US[1]) / 1024 - (SERVO_RANGE_US[1] / 2);
  int y2 = (sy * SERVO_RANGE_US[2]) / 1024 - (SERVO_RANGE_US[2] / 2);
  int t3 = (st * SERVO_RANGE_US[3]) / 1024;

  p.servo_write[0] = constrain(SERVO_TRIM_US[0] + x0, 1000, 2000);
  p.servo_write[1] = constrain(SERVO_TRIM_US[1] + x1, 1000, 2000);
  p.servo_write[2] = constrain(SERVO_TRIM_US[2] + y2, 1000, 2000);
  p.servo_write[3] = constrain(SERVO_TRIM_US[3] + t3, 1000, 2000);

  // packet ID
  p.rtt_timer = ++nextPacketId;
}

// ======================================================
bool radioHandler(Packet_TX &send, Packet_RX &receive) {
  inputHandler(send);
  awaitedPacketId = send.rtt_timer;

  radio.stopListening();
  radio.write(&send, sizeof(send));
  radio.startListening();

  bool gotReply = false;
  uint32_t waitStart = millis();

  // Since the radio-only test worked, wait briefly for matching echo
  while (millis() - waitStart < 30) {
    if (radio.available()) {
      Packet_RX temp;
      radio.read(&temp, sizeof(temp));

      if (temp.rtt_timer == awaitedPacketId) {
        receive = temp;
        lastLinkTime = millis();
        linkOK = true;
        gotReply = true;
        replyCount++;
        break;
      }
    }
  }

  if (millis() - lastLinkTime > 100) {
    linkOK = false;
  }

  debugOutput(send, receive, gotReply);

  // Green only when actually receiving matching plane data
  if (gotReply) {
    led[0] = CRGB(0, 255 - BRIGHTNESS, 0);
  } else {
    led[0] = CRGB(255 - BRIGHTNESS, 0, 0);
  }

  FastLED.show();
  return gotReply;
}

// ======================================================
void debugOutput(const Packet_TX &p, const Packet_RX &r, bool gotReply) {
  static uint32_t lastPrint = 0;
  uint32_t now = millis();

  if (now - lastPrint < 100) return;
  lastPrint = now;

  Serial.print("RX_OK: ");
  Serial.print(gotReply ? "YES" : "NO");

  Serial.print(" | LINK: ");
  Serial.print(linkOK ? "OK" : "LOST");

  Serial.print(" | TX_ID: ");
  Serial.print(p.rtt_timer);

  Serial.print(" | WAIT_ID: ");
  Serial.print(awaitedPacketId);

  Serial.print(" | ECHO_ID: ");
  Serial.print(r.rtt_timer);

  Serial.print(" | REPLIES: ");
  Serial.print(replyCount);

  Serial.print(" | SERVO: ");
  for (int i = 0; i < 4; i++) {
    Serial.print(p.servo_write[i]);
    if (i < 3) Serial.print(", ");
  }

  Serial.print(" | GYRO: ");
  Serial.print(r.gyro_x);
  Serial.print(", ");
  Serial.print(r.gyro_y);
  Serial.print(", ");
  Serial.print(r.gyro_z);

  Serial.println();
}

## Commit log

2026-04-16 BIG update
    [Controller_V2-schem.kicad_pcb, Controller_V2-schem.kicad_sch, Plane_v2.kicad_pcb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]
2026-04-16 Update BOM Links formatting and section headers
2026-04-16 Update formatting of BOM Links section
2026-04-16 Fix header formatting in BOM-Links.md
2026-04-16 Change header from H1 to H2 in BOM Links
2026-04-16 Updated BOM
2026-04-21 Added Schematics
    [Controller_Final.kicad_pcb, Controller_Final.kicad_sch, Plane_Final.kicad_pcb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]
2026-04-21 Changed file tree
    [Controller_Final.kicad_pcb, Controller_Final.kicad_sch, Controller_V2-schem.kicad_pcb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]
2026-04-25 updated schematics
    [Controller_Final.kicad_sch]
2026-04-25 Updated report and added cad folder
2026-06-02 switched flight test file type
